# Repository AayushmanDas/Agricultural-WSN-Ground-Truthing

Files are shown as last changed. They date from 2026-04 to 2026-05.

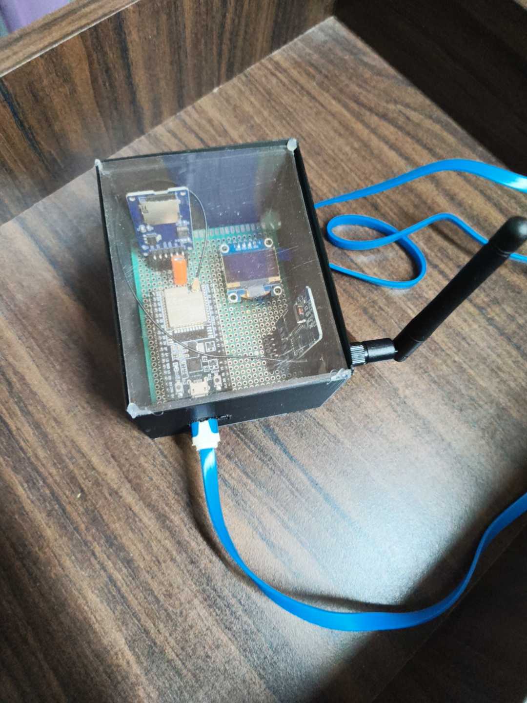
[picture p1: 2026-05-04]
media/images/IMG_20260322_044031079.jpg

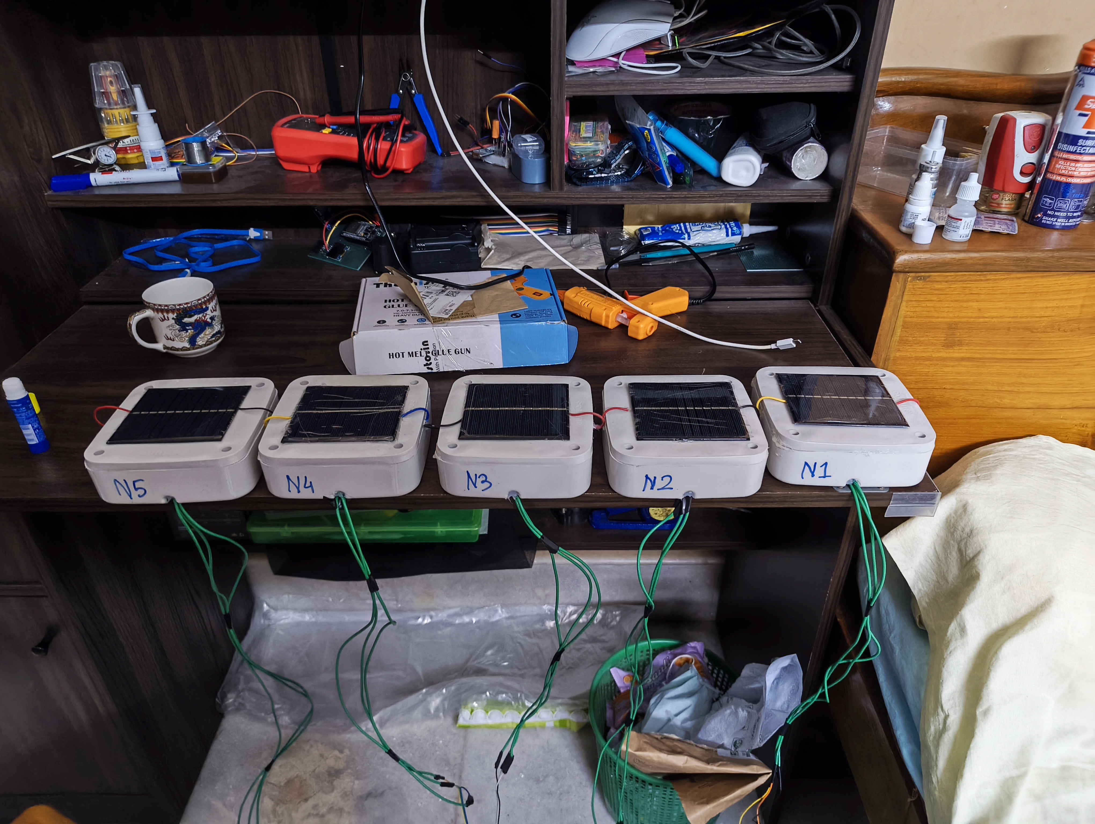
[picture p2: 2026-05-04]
media/images/IMG_20260323_042032066.jpg

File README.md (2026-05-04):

# Agricultural WSN Ground-Truthing
**Bridging the gap between orbital soil moisture observations and high-fidelity terrestrial in-situ data.**






## 📡 Research Objective
This framework is an end-to-end Wireless Sensor Network (WSN) designed to provide a local baseline for the validation of NASA's SMAP (Soil Moisture Active Passive) satellite products. By deploying synchronized sensor nodes in tropical micro-climates, the system identifies localized discrepancies that 9km orbital estimates cannot resolve.

## 🚀 Key Research Findings
* **Urban Resolution Gap:** Identified a **39.30% RMSE** discrepancy between orbital data and ground truth, suggesting significant spatial averaging bias in regional satellite products.
* **Environmental Resilience:** Maintained 100% data continuity for critical reference nodes during a **severe hailstorm (March 26)** through a triple-redundant logging pipeline.
* **Hydrological Dynamics:** Captured distinct moisture drying slopes ($m \approx -4.2\%/day$) influenced by urban verticality and micro-climatic "pockets."

## 🏗️ Technical Architecture
* **Protocol:** Optimized **ESP-NOW** (1 Mbps Long Range) for robust peer-to-peer data acquisition through reinforced concrete environments.
* **Power Management:** Custom Li-ion harvesting with **HT7333-A LDOs** (4µA quiescent current) and deep-sleep optimization for maximum field longevity.
* **Triple-Redundancy Pipeline:** 1. **Local:** Real-time OLED telemetry.
    2. **Edge:** SPI-based SD card logging (DS3231 RTC synchronized).
    3. **Cloud:** PostgreSQL (Supabase) sync via asynchronous Wi-Fi handshakes.

## 📂 Repository Structure
* **/firmware** - Source code for Central Hub & Remote Nodes.
* **/hardware** - Fusion 360 CAD models, KiCad schematics and BOM.
* **/scripts** - Python scripts for heuristic noise reduction and NASA SMAP correlation.
* **/docs** - Full IEEE-format technical paper and technical abstract.
* **/media** - Images and Video links showcasing the production procedure.

## 🛠️ Hardware Specifications
| Component | Detail |
| :--- | :--- |
| **Microcontroller** | ESP32-WROOM-32 |
| **Atmospheric Sensor** | BME280 (Temperature, Humidity, Pressure) |
| **Soil Sensor** | Capacitive v1.2 (Potded/Ruggedized) |
| **Regulation** | HT7333-A Low-Dropout Regulator |
| **Casing** | Custom 3D-printed Hub + IP65 Field Enclosures |

## ⚖️ Citation
If you utilize this framework or dataset, please cite the preprint:
> Das, A. (2026). "Robustness Evaluation of a Low-Cost WSN for Satellite Ground-Truthing under Extreme Tropical Weather Events." ResearchGate. DOI: [10.13140/RG.2.2.25746.00967](https://doi.org/10.13140/RG.2.2.25746.00967)

---
**Maintained by Aayushman Das** *Department of Electronics and Telecommunication Engineering, Jadavpur University*

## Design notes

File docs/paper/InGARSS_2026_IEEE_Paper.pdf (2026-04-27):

# Robustness Evaluation of a Low-Cost WSN for Satellite Ground-Truthing under Extreme Tropical Weather Events

Aayushman Das
Department of Electronics and Telecommunication Engineering Jadavpur University
Kolkata, India
aayushmand.etce.ug@jadavpuruniversity.in

Abstract—Satellite missions like NASA’s SMAP provide global soil moisture estimates but their 9km spatial resolution necessitates terrestrial validation. However, deploying low-cost Wireless Sensor Networks (WSNs) in tropical micro-climates presents significant reliability challenges. This paper evaluates the performance of an ESP32 based 5-node Wireless Sensor Network (WSN) during a hailstorm and subsequent thunderstorm events in West Bengal. Utilizing the ESP-NOW protocol and a tripleredundant data pipeline (OLED, SD, Cloud), we analyze system resilience and sensor recovery dynamics. Despite a high node attrition rate due to extreme precipitation, the framework maintained data continuity for critical reference nodes. Our findings hope to show that modularity and redundancy are vital for validation systems where environmental ”failure points” define the boundaries of satellite-to-ground correlation.
Index Terms—Wireless Sensor Networks, Ground-Truthing, ESP32, ESP-NOW, NASA SMAP, Soil Moisture, Triple Redundant Pipeline.
I. INTRODUCTION

Satellite data is essential to contemporary environmental science however, its lack of spatial resolution restricts its use in small-scale farming. For example, NASA’s SMAP mission usually yields a reading every 9 kilometers. Inaccurate averages for specific farm plots may result from this. There is a ”trust-gap” in remote sensing for regional use, as evidenced by a local survey of over 50 respondents, which revealed that about 80% of users trust a local sensor more than a satellite reading. Reliable, inexpensive terrestrial systems are obviously needed to confirm what satellites are seeing from orbit [1]. Our goal at Jadavpur University is to develop high-precision research instruments on a tight budget. The objective is to achieve industrial-grade reliability without the expense of pricey commercial equipment, much like ISRO’s inventiveness. Long-range work frequently uses protocols like LoRa, but each node needs extra hardware to use them. Rather, we improved the ESP-NOW protocol, which is integrated into the ESP32. We established a reliable link that can pass through four to five layers of reinforced concrete by utilizing 1 Mbps Long Range mode and high-gain SMA antennas at the hub. While commercial agro-meteorological stations (e.g., Davis Vantage Pro2) offer high accuracy, their cost-per-node (>500

USD) makes high density urban deployment problematic [8]. Our ESP32-based architecture, costing ≈ 15 USD per node, provides a scalable alternative for capturing the high spatial variance of urban micro-climates [11].
The goal of this study is to determine the correlation error between orbital estimates and ground truth while evaluating the structural resilience of the WSN itself. The setup maintains its scientific validity even in the event of hardware or network disruptions by utilizing a triple redundant data pipeline (OLED, SD and Cloud). A unique aspect of this deployment was the occurrence of a severe hailstorm during the 14 day window, which turned the project into a stress test for low-cost hardware. Python is used to process the data and for filtering out hardware artifacts caused by moisture deposition. The source code and hardware design files are available at https://github.com/AayushmanDas/Agricultural-WSN-Ground-Truthing. (https://github.com/AayushmanDas/Agricultural-WSN-Ground-Truthing)

II. METHODOLOGY

A. Node Hardware Design and Power Management

The sensor nodes can function independently for extended periods of time in agricultural settings with high humidity. Each node is powered by a single 18650 Li-ion battery that is charged using a TP4056 module and a 6V 250mA solar panel. Power is controlled by an HT7333-A Low-Dropout (LDO) regulator, which was chosen for its extremely low quiescent current (4µA) to reduce current draw during inactive times. In order to save energy, the ESP32 uses a Deep Sleep cycle, sending data ”chirps” every 30 minutes and staying in a lowpower state the rest of the time.
The sensors consisted of a BME280, for atmospheric data and a capacitive soil moisture probe. The BME280 is configured for I2C communication, the CS pin is pulled high to force I2C mode, and the SDO pin is tied to 3.3V to lock the I2C address at 0x77. Soil moisture is monitored via an analog-to-digital converter (ADC) on GPIO 34 [4], [5]. A 25V rated voltage divider (7kΩ/10kΩ) provides battery telemetry, allowing the system to monitor charge cycles.

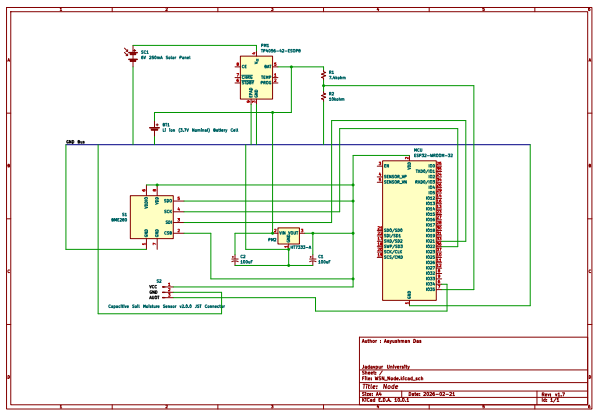
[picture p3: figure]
D Date: 2026-02-21; KiCad E.D.A. 10.0.1; Size: A4; Rev: v1.7; Title: Node; File: WSN_Node.kicad_sch; Sheet: /; Jadavpur University; Author : Aayushman Das; TEMP 1 PROG 2 GND; V CC 4 BAT 5; STDBY 6 CHRG 7 CE 8; EPAD; TP4056-42-ESOP8; GND; 1 VDD; SENSOR_VP 4 SENSOR_VN 5; SHD/SD2 17 SWP/SD3 18 SCS/CMD 19 SCK/CLK 20; SDO/SD0 21 SDI/SD1 22; IO21 33 RXD0/IO3 34; TXD0/IO1 35; IO23 37 MCU; ESP32-WROOM-32 R1 7.4kohm; R2 10kohm; SC1 6V 250mA Solar Panel BT1; Li ion (3.7V Nominal) Battery Cell; 100uF GND; 1 CSB 2; SDI 3; SCK 4; SDO 5 VDDIO; 6 GND 7 VDD; S1 BME280; VIN 2; VOUT 3 PM2; AUOT GND Bus; VCC

S2 Capacitive Soil Moisture Sensor v2.0.0 JST Connector | C2

Fig. 1. Circuit diagram of the solar-powered sensor node. Key components include the HT7333-A LDO for low-quiescent current and the TP4056

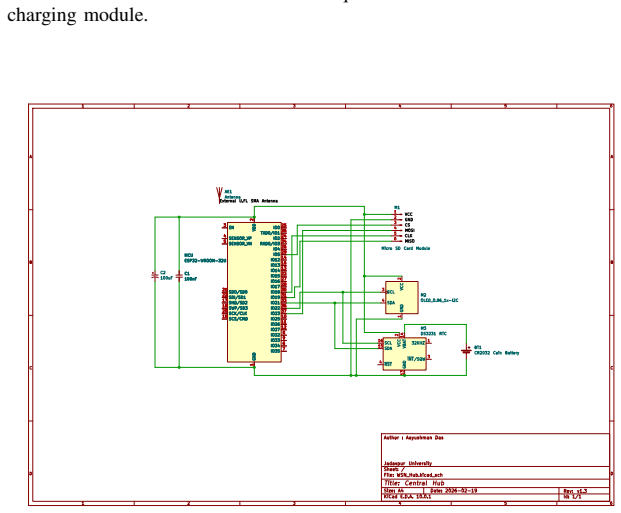
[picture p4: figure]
charging module. 1; D Date: 2026-02-19; KiCad E.D.A. 10.0.1; Size: A4; Rev: v1.3; Title: Central Hub; File: WSN_Hub.kicad_sch; Sheet: /; Jadavpur University; Author : Aayushman Das C2; GND; 1 VDD; SENSOR_VP 4 SENSOR_VN 5; SHD/SD2 17 SWP/SD3 18 SCS/CMD 19 SCK/CLK 20; SDO/SD0 21 SDI/SD1 22; IO21 33 RXD0/IO3 34; TXD0/IO1 35; IO23 37 MCU ESP32-WROOM-32U; AE1 Antenna C1; INT/SQW 3 RST 4; GND 13 VBAT 14; SDA 15 SCL 16; M3 DS3231 RTC GND; 1 VCC; SCL 3; SDA 4; M2 OLED_0.96_1x-I2C; VCC; CSCLK MISO MOSI C1; 100nF MCU; ESP32-WROOM-32U

100nF | BT1 CR2032 Coin Battery 32KHZ 1 VCC
6M1 Micro SD Card Module External U.FL SMA Antenna | GND

Fig. 2. Gateway (Hub) schematic illustrating the SPI interface for the SD module and the I2C bus sharing between the 0.96 inch SSD1306 OLED and DS3231 RTC module.

B. Gateway (Hub) Architecture and Redundancy

The hub serves as a link between the cloud and the local WSN. It has an 0.96 inch OLED for telemetry and a DS3231 Real Time Clock (RTC) Module to preserve time-stamping accuracy during power cycles. It is powered by a 5V micro USB supply. To avoid data loss during network outages, data is locally stored on an SPI-based SD card module.
A Triple Redundant Data Pipeline was used, aiming to improve data integrity. The Hub uploads a snapshot of the most recent data to a Supabase PostgreSQL database every three hours, but it gives priority to ESP-NOW packet reception. The WiFi stack only initialises if no node packets have been received in the previous 5-minute buffer, preventing radio interference.
C. Firmware Implementation and Time-Division Radio Multiplexing
It takes careful timing to manage two different radio protocols on the same 2.4 GHz antenna. It was necessary to use a Time-Division Hardware Re-initialization strategy because standard 802.11 WiFi and 1 Mbps Long Range ESP-NOW (fixed on Channel 1) cannot work at the same time without losing a ton of packets [3]. The Hub’s default setting is to keep an active ESP-NOW listening state. When the threehour cloud-sync timer goes off, the firmware does a Complete Radio De-initialization. This clears the ESP-NOW stack from memory and sets up the hardware registers for a standard WiFi handshake. The ArduinoJson library serialises the data, and an asynchronous HTTP POST request sends it to the Supabase REST API. Once a ”200 OK” response is verified, the WiFi stack is terminated, and the radio is recalibrated back to its high gain ESP-NOW state.
D. Enclosure and Environmental Ruggedization
The Hub enclosure was modeled in Fusion 360 and 3D printed using PLA material (20% infill, 78g). The field nodes are placed in IP65-rated enclosures. To withstand the humid climate, all wire entry points were sealed with neutral silicone sealant and hot glue. A semi permeable vent was placed at the base of each box to allow airflow for the BME280 while blocking entry of insects like ants and spiders.
The capacitive soil sensors underwent a ”potting” process, where exposed surface-mount components were coated in silicone to prevent oxidation. Nodes were deployed with the enclosures elevated 0.5m above the ground to improve Fresnel zone clearance.
E. Deployment and Field Observation
In order to track a 14 day cycle, the system was installed in a home garden in Kolkata, West Bengal. Nodes were positioned 0.5m above the ground, in order to improve link quality. The network’s average Received Signal Strength Indicator (RSSI) was consistently between -80 to -85 dBm, according to real time telemetry on the Hub’s OLED interface.
The optimized 1 Mbps Long Range mode maintained a stable link despite the highly resistive path to Node 4, which required diagonal signal penetration through approximately 0.8m of reinforced concrete. A modular hardware design facilitated rapid field recovery following a mechanical impact on Node 1 during the initial deployment. While the impact compromised the soil probe and voltage divider, the digital I2C atmospheric sensor remained operational. This incident led to a design iteration where all node mounting points were secondary reinforced with fasteners, increasing the structural damping of the enclosures for the remainder of the study.
F. Environmental Stress and Node Attrition
The 14-day observational window was characterized by significant meteorological volatility, including a localized hailstorm on March 26, 2026, followed by recurring thunderstorms. These events resulted in a 60% network attrition rate, providing a natural stress-test for the system. Node 1 experienced terminal power failure, while Nodes 3 and 4 showed oscillator stall issues, a state where moisture deposition on the capacitive sensor heads shifts the resonant frequency beyond operational bounds. Conversely, Node 2 (elevated at 1.5m) and Node 5 (terrace-mounted) maintained data continuity. This suggests that high-ventilation placement is more critical for long term IP65 enclosure integrity than physical shielding, as the sheltered nodes suffered from moisture trapping and prolonged humidity exposure.

III. DATA POST-PROCESSING AND ANALYTICS

A. Heuristic Noise Reduction and Outlier Filtering
Raw field data from the WSN exhibited significant stochastic noise, primarily attributed to high-frequency dielectric fluctuations during extreme precipitation. To ensure scientific integrity, a multi-stage Python-based cleaning pipeline was implemented.
- Hard-Clamp Filter: A signal-to-physical range mapping was applied to moisture readings. Values below 30% (designating dry-air reference) and above 100% (saturation) were designated as null (N aN). This eliminated hardware-induced transients and ADC jitter caused by supply voltage fluctuations during solar charging cycles.
- Stale-Data Detector: To identify sensor freezing, a rolling standard deviation filter monitored readings over a 6 hour window (12 samples). Any node exhibiting zero variance (σ = 0) was flagged as an oscillator stall and excluded. This condition typically occurs when moisture deposition on the capacitive sensor head shifts the resonant frequency beyond the operational bounds of the internal timer circuit.
- Timestamp Correction: Due to the absence of a global clock on individual nodes, temporal drift was corrected by the Hub’s DS3231 RTC. Records with corrupted Unix timestamps (e.g., year 2045 artifacts) were re-mapped based on the sequential index of the SD card logs.
B. Spatial-Temporal Alignment with Orbital Products
NASA SMAP (Level-3 Passive) data provides a singular daily estimate at a 9km spatial resolution. Conversely, the WSN provided 48 samples per day (30-minute chirps). To allow for cross-validation, the WSN dataset was down sampled using a nearest neighbor temporal join to the specific overpass timestamp provided in the SMAP metadata [2]. This attempts to ensure that ground-truth data reflected the exact soil state at the moment of orbital sensing.

IV. EXPERIMENTAL RESULTS AND DISCUSSION

A. Network Resilience and Attrition Dynamics
As illustrated in Fig. 3, the network faced severe environmental stress during the localized hailstorm on March 26, 2026. While Nodes 1, 3, and 4 suffered hardware failure, Node 2 and Node 5 maintained continuity.
This disparity in survival provides critical insights into urban WSN deployment. Nodes 3 and 4 were ”sheltered” under a canopy, which paradoxically led to their failure, the canopy trapped high humidity and slowed evaporation, leading to prolonged moisture deposition in the enclosures. Conversely, Node 2 (elevated at 1.5m) and Node 5 (terrace-mounted) benefited from higher wind velocity and ventilation, which facilitated rapid drying of the external housing. This suggests that for tropical WSNs, ventilation is a more effective strategy than physical shielding for long term use cases.

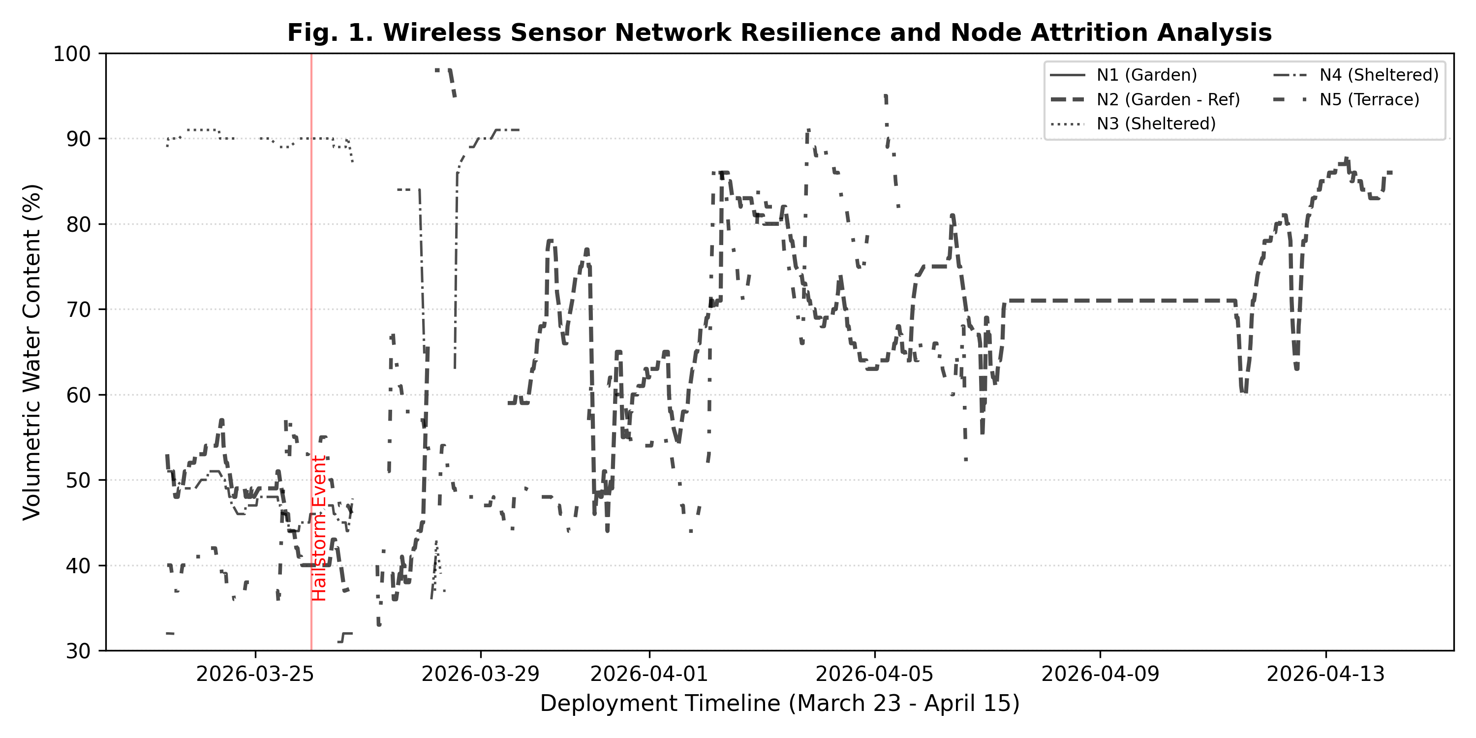
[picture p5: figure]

Fig. 3. WSN Attrition Analysis: Visualization of node failure points relative to the March 26 hailstorm ingress. Discontinuities represent data cleaning via the stale-data filter.

B. Vertical Microclimate Variance
A significant moisture gradient was observed between ground-level (Node 2) and terrace-level (Node 5) deployments (Fig. 4). While both nodes recorded a saturation spike during the hailstorm, Node 5 exhibited a steeper drying slope (m ≈ −4.2%/day).
This confirms that urban verticality influences moisture retention. High-elevation ”pockets” (terraces) experience different evaporative microclimates than ground-level gardens. Because satellite sensors (9km pixels) average these heights into a single value, they fail to resolve the distinct hydrological behaviors required for precision urban agricultural management.

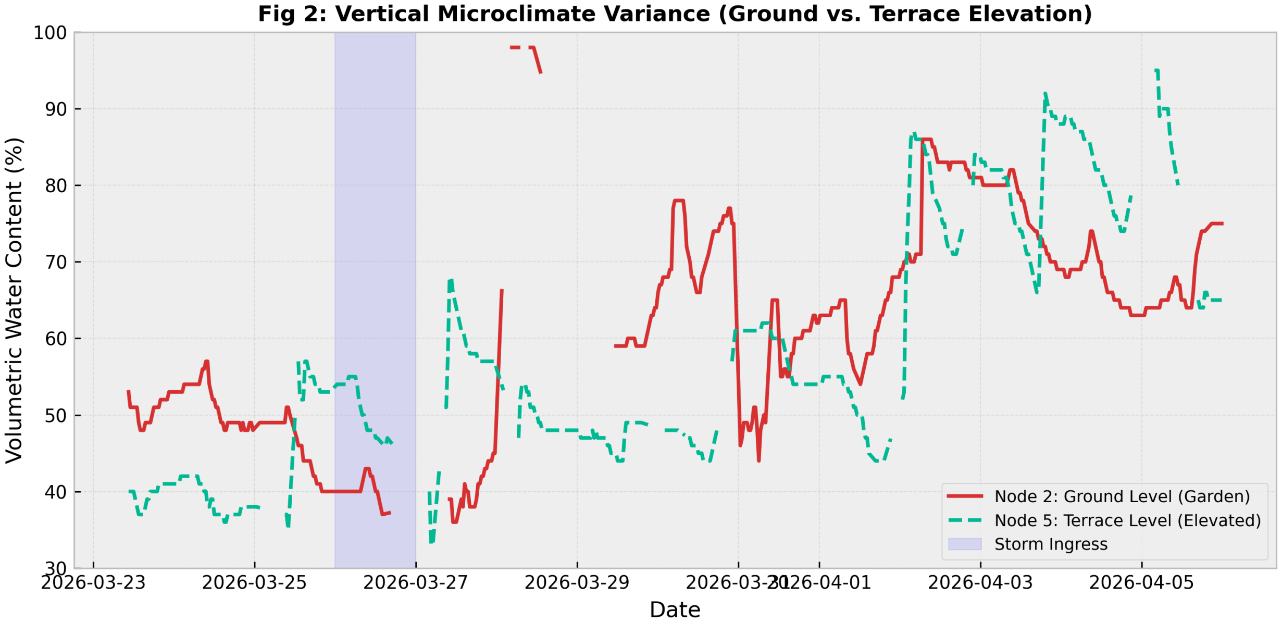
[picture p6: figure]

Fig. 4. Vertical Microclimate Variance: Comparing Ground-Truth (Node 2) vs. Terrace-Level (Node 5) moisture retention dynamics.

C. Satellite Validation and the ’Urban Bias’ Gap
The cross-validation against NASA SMAP (Fig. 5) yielded an RMSE of 39.30% and a correlation of -0.33. While these metrics initially suggest failure, in an urban context they highlight the Urban Resolution Gap [10]. The 9km SMAP footprint averages vast non-porous surfaces, resulting in a mean estimate (29.72%) that significantly underestimates localized vegetative hotspots (65.40%). The negative correlation further underscores the impact of anthropogenic factors, such as the shaded, manually-watered container at Node 5, which orbital sensors cannot resolve [7].

TABLE I
WSN VS. NASA SMAP ACCURACY METRICS SUMMARY
Metric | Value | Engineering Significance
RMSE (%) | 39.30% | Evidence of Spatial Averaging Bias
Trend Correlation (ρ) | -0.33 | Anthropogenic/Microclimate Decoupling
Mean WSN Value | 65.40% | High-Resolution In-Situ Ground Truth
Mean SMAP Value | 29.72% | Regional Coarse-Resolution Average

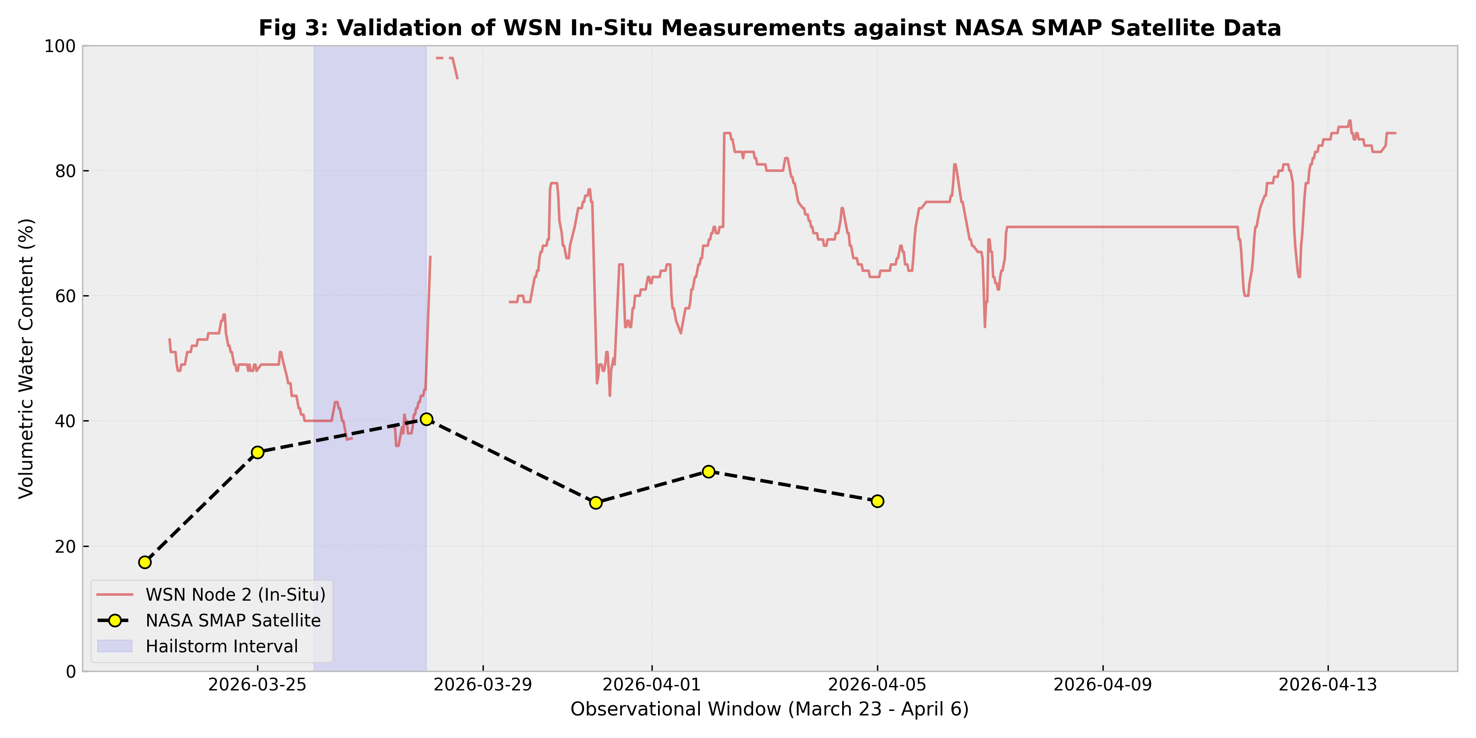
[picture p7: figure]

Fig. 5. In-Situ WSN vs. NASA SMAP: High RMSE highlights the Underestimation Bias in satellite products for urban vegetative hotspots.

V. LIMITATIONS AND FUTURE WORK
A. Study Limitations
We acknowledge that as a student led pilot study, the deployment scale was limited to five nodes within a specific residential microclimate. The 2 week observational window, while providing intense data during a hailstorm, may not capture long term seasonal shifts. Furthermore, the high attrition rate (60%) underscores that current low-cost IP65 enclosures require additional mechanical reinforcement to serve as permanent infrastructure in volatile tropical regions.
B. Concluding Remarks
Despite scale constraints, the surviving nodes exposed a critical underestimation bias in NASA’s SMAP product. Terrestrial WSNs proved to be essential corrective layers for achieving hydrological accuracy in urban centers where satellite pixels fail to resolve irrigation and verticality [6].
C. Future Research Directions
The results of this deployment establish a foundation for several engineering advancements:
- NISAR Integration: Future validation will prioritize NISAR’s high-resolution radar data to investigate if SAR products can bridge the 39.3% accuracy gap [9].
- Hardware Ruggedization: Testing superhydrophobic nano-coatings on enclosure vents to prevent moistureinduced frequency stalls.
- Edge-AI Implementation: Porting cleaning algorithms directly onto the ESP32 using TinyML for on-device autonomous outlier handling.
- Hybrid Power Management: Utilizing supercapacitorbattery hybrids to ensure 100% operational uptime, especially during monsoon periods.

ACKNOWLEDGMENT
The author acknowledges the assistance of LLMS, such as Gemini and Claude in manuscript preparation, specifically for language refinement, LaTeX formatting, and providing structural templates for software logic. These tools were utilized to optimize the C++ time-division radio firmware and refine the Python-based data cleaning scripts.
The author confirms that the physical hardware architecture, including solar power management and the 5-node WSN configuration and the 14-day field deployment were performed independently. While AI assisted in software logic and documentation, the author assumes responsibility for the manuscript’s conclusions and the overall scientific integrity of this paper.

REFERENCES

[1] D. Entekhabi et al., ”The Soil Moisture Active and Passive (SMAP) mission,” Proceedings of the IEEE, vol. 98, no. 5, pp. 704–716, May 2010, doi: 10.1109/JPROC.2010.2043918.
[2] A. Colliander et al., ”Validation of SMAP surface soil moisture products with core validation sites,” Remote Sensing of Environment, vol. 191, pp. 215–231, 2017, doi: 10.1016/j.rse.2017.01.021.
[3] Espressif Systems, ”RF Coexistence,” ESP-IDF Programming Guide, Espressif Systems (Shanghai) Co., Ltd., 2023. [Online]. Available: https://docs.espressif.com/projects/esp-idf/en/stable/esp32/apiguides/coexist.html
[4] A. A. Abdelmoneim, C. M. Al Kalaany, R. Khadra, B. Derardja, and G. Dragonetti, ”Calibration of Low-Cost Capacitive Soil Moisture Sensors for Irrigation Management Applications,” Sensors, vol. 25, no. 2, p. 343, Jan. 2025, doi: 10.3390/s25020343.
[5] P. Placidi, L. Gasperini, A. Grassi, M. Cecconi, and A. Scorzoni, ”Characterization of Low-Cost Capacitive Soil Moisture Sensors for IoT Networks,” Sensors, vol. 20, no. 12, p. 3585, Jun. 2020, doi: 10.3390/s20123585.
[6] L. Brocca, L. Ciabatta, C. Massari, S. Camici, and A. Tarpanelli, ”Soil Moisture for Hydrological Applications: Open Questions and New Opportunities,” Water, vol. 9, no. 2, p. 140, 2017, doi: 10.3390/w9020140.
[7] NASA SMAP Science Document No. 046, ”SMAP Ancillary Data Report: Urban Area,” Jet Propulsion Laboratory, Pasadena, CA, USA, Tech. Rep., 2014. [Online]. Available: https://smap.jpl.nasa.gov/
[8] N. Ahmad, A. Hussain, I. Ullah, and B. H. Zaidi, ”IOT based Wireless Sensor Network for Precision Agriculture,” in Proc. iEECON, 2019, pp. 1–4, doi: 10.1109/iEECON45304.2019.8938854.
[9] P. Rosen et al., ”The NASA-ISRO SAR Mission: A summary,” IEEE Geosci. Remote Sens. Mag., 2025, doi: 10.1109/MGRS.2025.3578258.
[10] W. Liu et al., ”Validation of Four Satellite-Derived Soil Moisture Products Using Ground-Based In Situ Observations over Northern China,” Remote Sens., vol. 14, no. 6, p. 1419, 2022, doi: 10.3390/rs14061419.
[11] S. Majumder et al., ”Assessing Low-cost Capacitive Soil Moisture Sensors: Accurate, Affordable, and IoT-ready Solutions for Soil Moisture Monitoring,” Int. J. Environ. Clim. Change, vol. 13, no. 11, pp. 2233– 2242, 2023, doi: 10.9734/ijecc/2023/v13i113386.

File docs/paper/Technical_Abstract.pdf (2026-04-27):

# Architecture of a Ground-Truthing System for Verified Agricultural Wireless Sensor Networks

Aayushman Das
Department of Electronics and Telecommunication Engineering Jadavpur University, Kolkata, India Documentation and Source Code: https://github.com/AayushmanDas/Agricultural-WSN-Ground-Truthing

Abstract

This project outlines an empirical architecture for a 5-node Wireless Sensor Network (WSN) designed to validate NASA SMAP orbital soil moisture data against localized terrestrial measurements. Due to the 9km spatial resolution of satellite products, urban and tropical micro-climates often suffer from high signal variance that necessitates high-fidelity ground-truthing.
The system is built on the ESP-NOW protocol, utilizing a high-gain 1 Mbps Long Range mode for penetration through environmental obstacles. Hardware nodes feature HT7333-A LDO regulators for ultra-low quiescent current consumption (4µA), supported by solarcharged 18650 Li-ion arrays for autonomous operation. A triple-redundant data pipeline was implemented—consisting of local SD logging, real-time OLED telemetry, and a Supabase cloud uplink—to ensure data persistence during extreme weather. Deployment during a localized hailstorm in West Bengal validated the system’s resilience, revealing a 39.30% RMSE bias in satellite data for urban hotspots. This framework demonstrates a scalable, low-cost method for correcting spatial averaging in remote sensing through high-fidelity IoT telemetry.

Keywords: Ground Truthing, NASA SMAP, ESP-NOW, Triple Redundant Pipeline, HT7333-A LDO, Urban Resolution Gap.

1

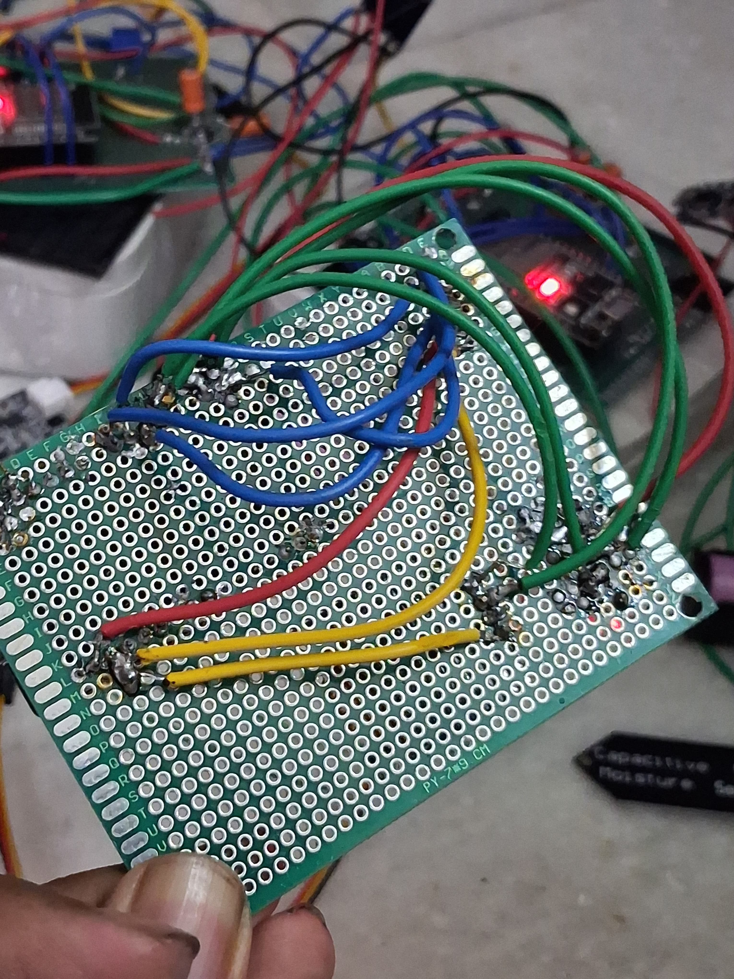
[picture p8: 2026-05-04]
media/images/IMG-20260217-WA0008.jpg

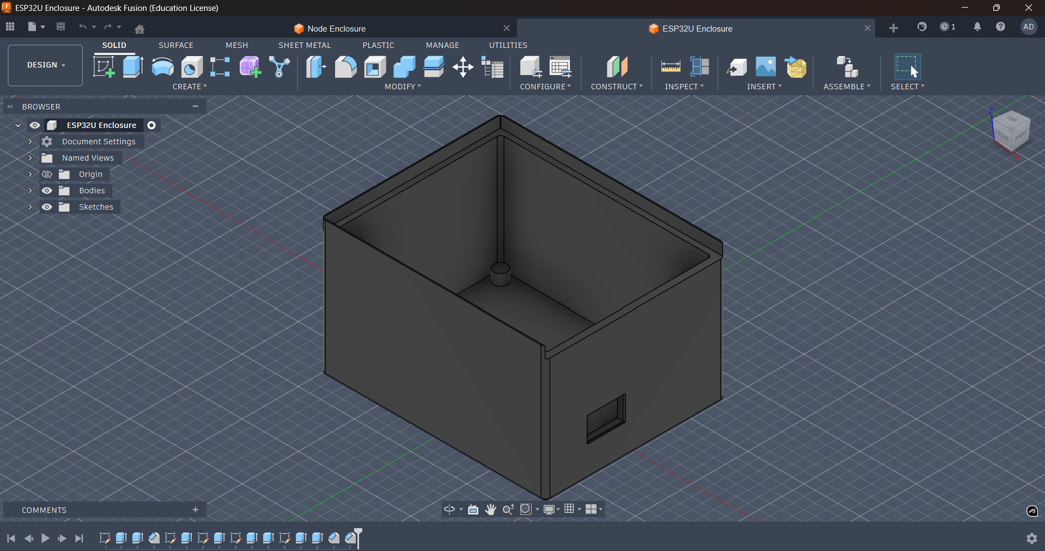
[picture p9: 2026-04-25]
media/images/1_ESP32U Enclosure Isometric View.png

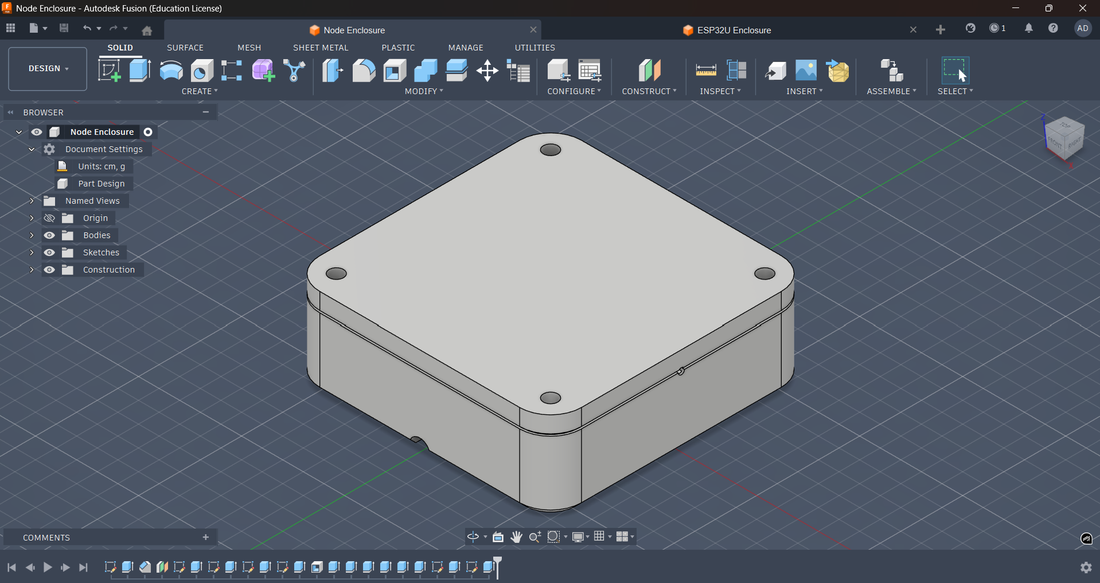
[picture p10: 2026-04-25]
media/images/5_Node Enclosure Isometric View.png

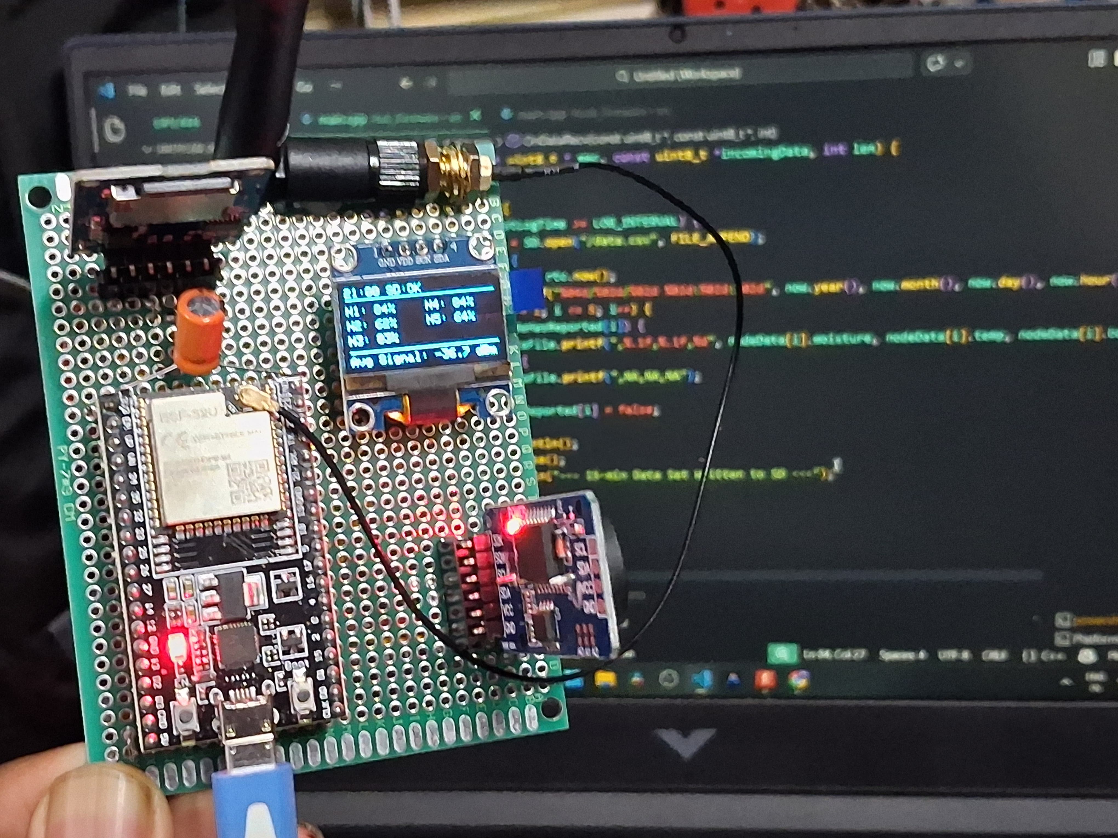
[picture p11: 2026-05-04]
media/images/IMG-20260217-WA0012.jpg

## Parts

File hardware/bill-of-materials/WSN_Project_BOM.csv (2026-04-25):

Category | Component | Specification | Purpose | Qty (Total)
Microcontrollers | ESP32-WROOM-32U | 38-Pin Wide (U.FL connector) | Central Hub MCU | 1
 | ESP32-WROOM-32 | 30-Pin Standard | Remote Node MCU | 5
Sensors | BME280 | I2C (Temp/Humid/Pressure) | Atmospheric Ground-Truthing | 6
 | SEN0193 | Capacitive Soil Moisture | Terrestrial Soil Moisture | 5
 | Voltage Sensor | VCC < 25V (0.1V Res.) | Battery/Solar Monitoring | 5
Power (Node) | HT7333-A | 3.3V Low Dropout (LDO) | Ultra-low power regulation | 5
 | TP4056 | 1A Li-ion Charging Module | Solar charging controller | 5
 | Solar Panel | 5V / 250mW (Monocrystalline) | Energy harvesting | 5
 | 18650 Battery | 3.7V Li-ion (2600mAh+) | Node power source | 5
Power (Hub) | Wall Adapter | 5V 1A Micro-USB/Type-C | Continuous Hub power | 1
Storage/Time | Micro SD Module | SPI Interface (5V Compatible) | Local Data Redundancy | 1
 | DS3231 RTC | I2C High-Accuracy Clock | Precise Data Timestamping | 1
Peripherals | OLED Display | 0.96" I2C (128x64) | Real-time Hub Telemetry | 1
 | SMA Antenna | 2.4GHz High Gain (External) | Long-range ESP-NOW link | 1
Hardware | IP65 Enclosures | Waterproof ABS Plastic | Field node protection | 5
 | Connectors | JST-PH 2.0 / Screw Terminals | Modular wiring | 10+

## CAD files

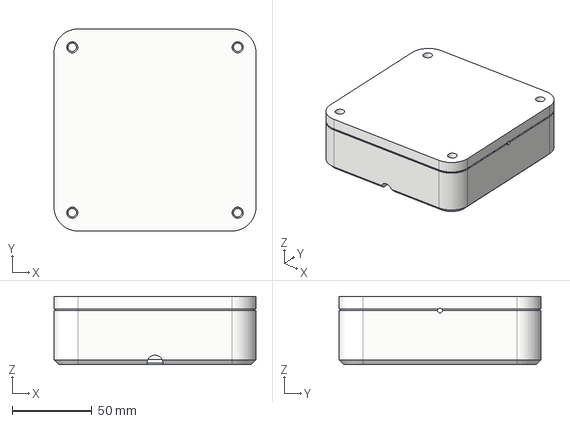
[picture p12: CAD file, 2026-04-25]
hardware/cad-models/Node Enclosure.step
127.0 x 127.0 x 43.0 mm

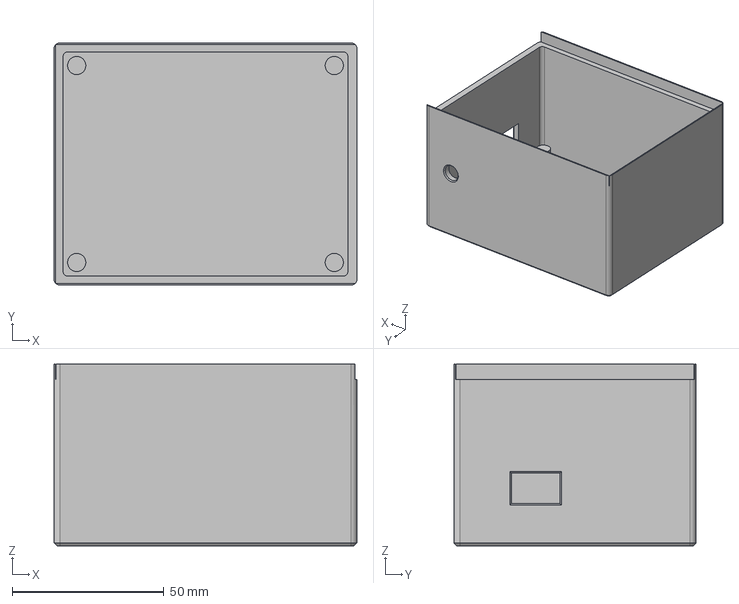
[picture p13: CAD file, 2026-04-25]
hardware/cad-models/ESP32U Enclosure.step
100.0 x 80.0 x 60.0 mm

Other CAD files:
hardware/cad-models/ESP32U Enclosure.f3d
hardware/cad-models/Node Enclosure.f3d

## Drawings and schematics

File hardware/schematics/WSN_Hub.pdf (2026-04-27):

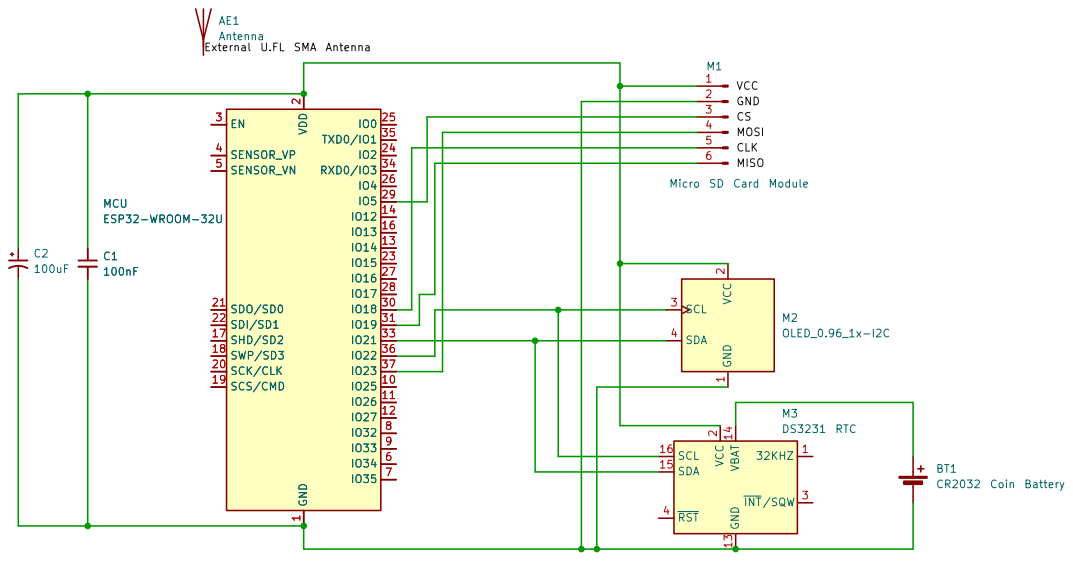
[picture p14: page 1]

Size: A4 | Rev: v1.3
KiCad E.D.A. 10.0.1 | Id: 1/1

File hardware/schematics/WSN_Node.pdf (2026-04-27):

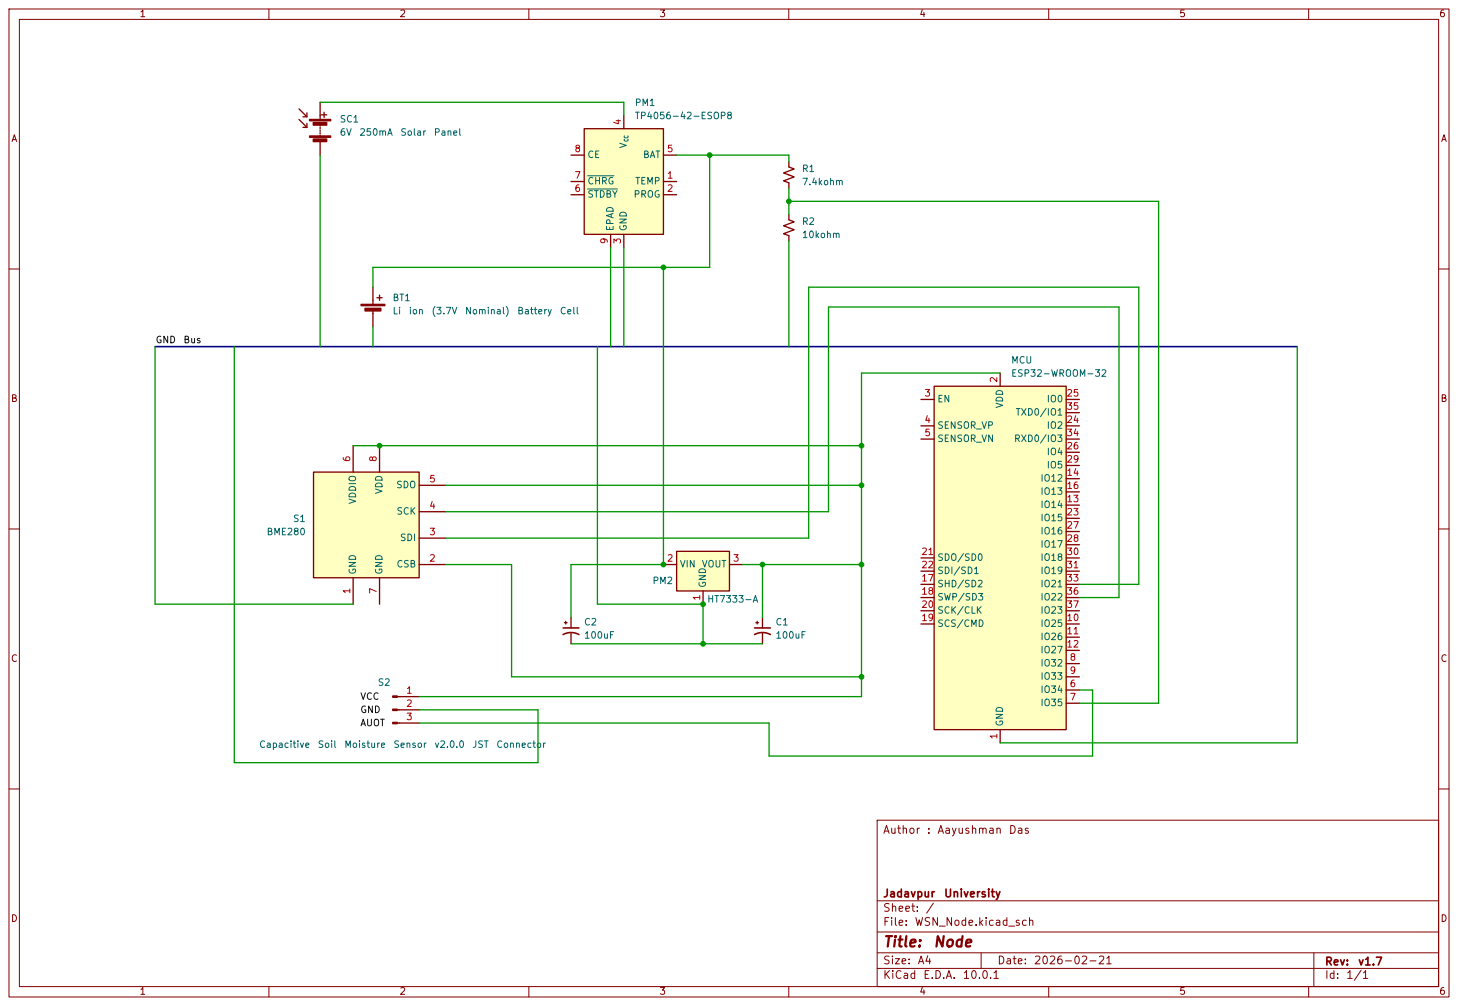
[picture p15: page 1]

Size: A4 | Rev: v1.7
KiCad E.D.A. 10.0.1 | Id: 1/1

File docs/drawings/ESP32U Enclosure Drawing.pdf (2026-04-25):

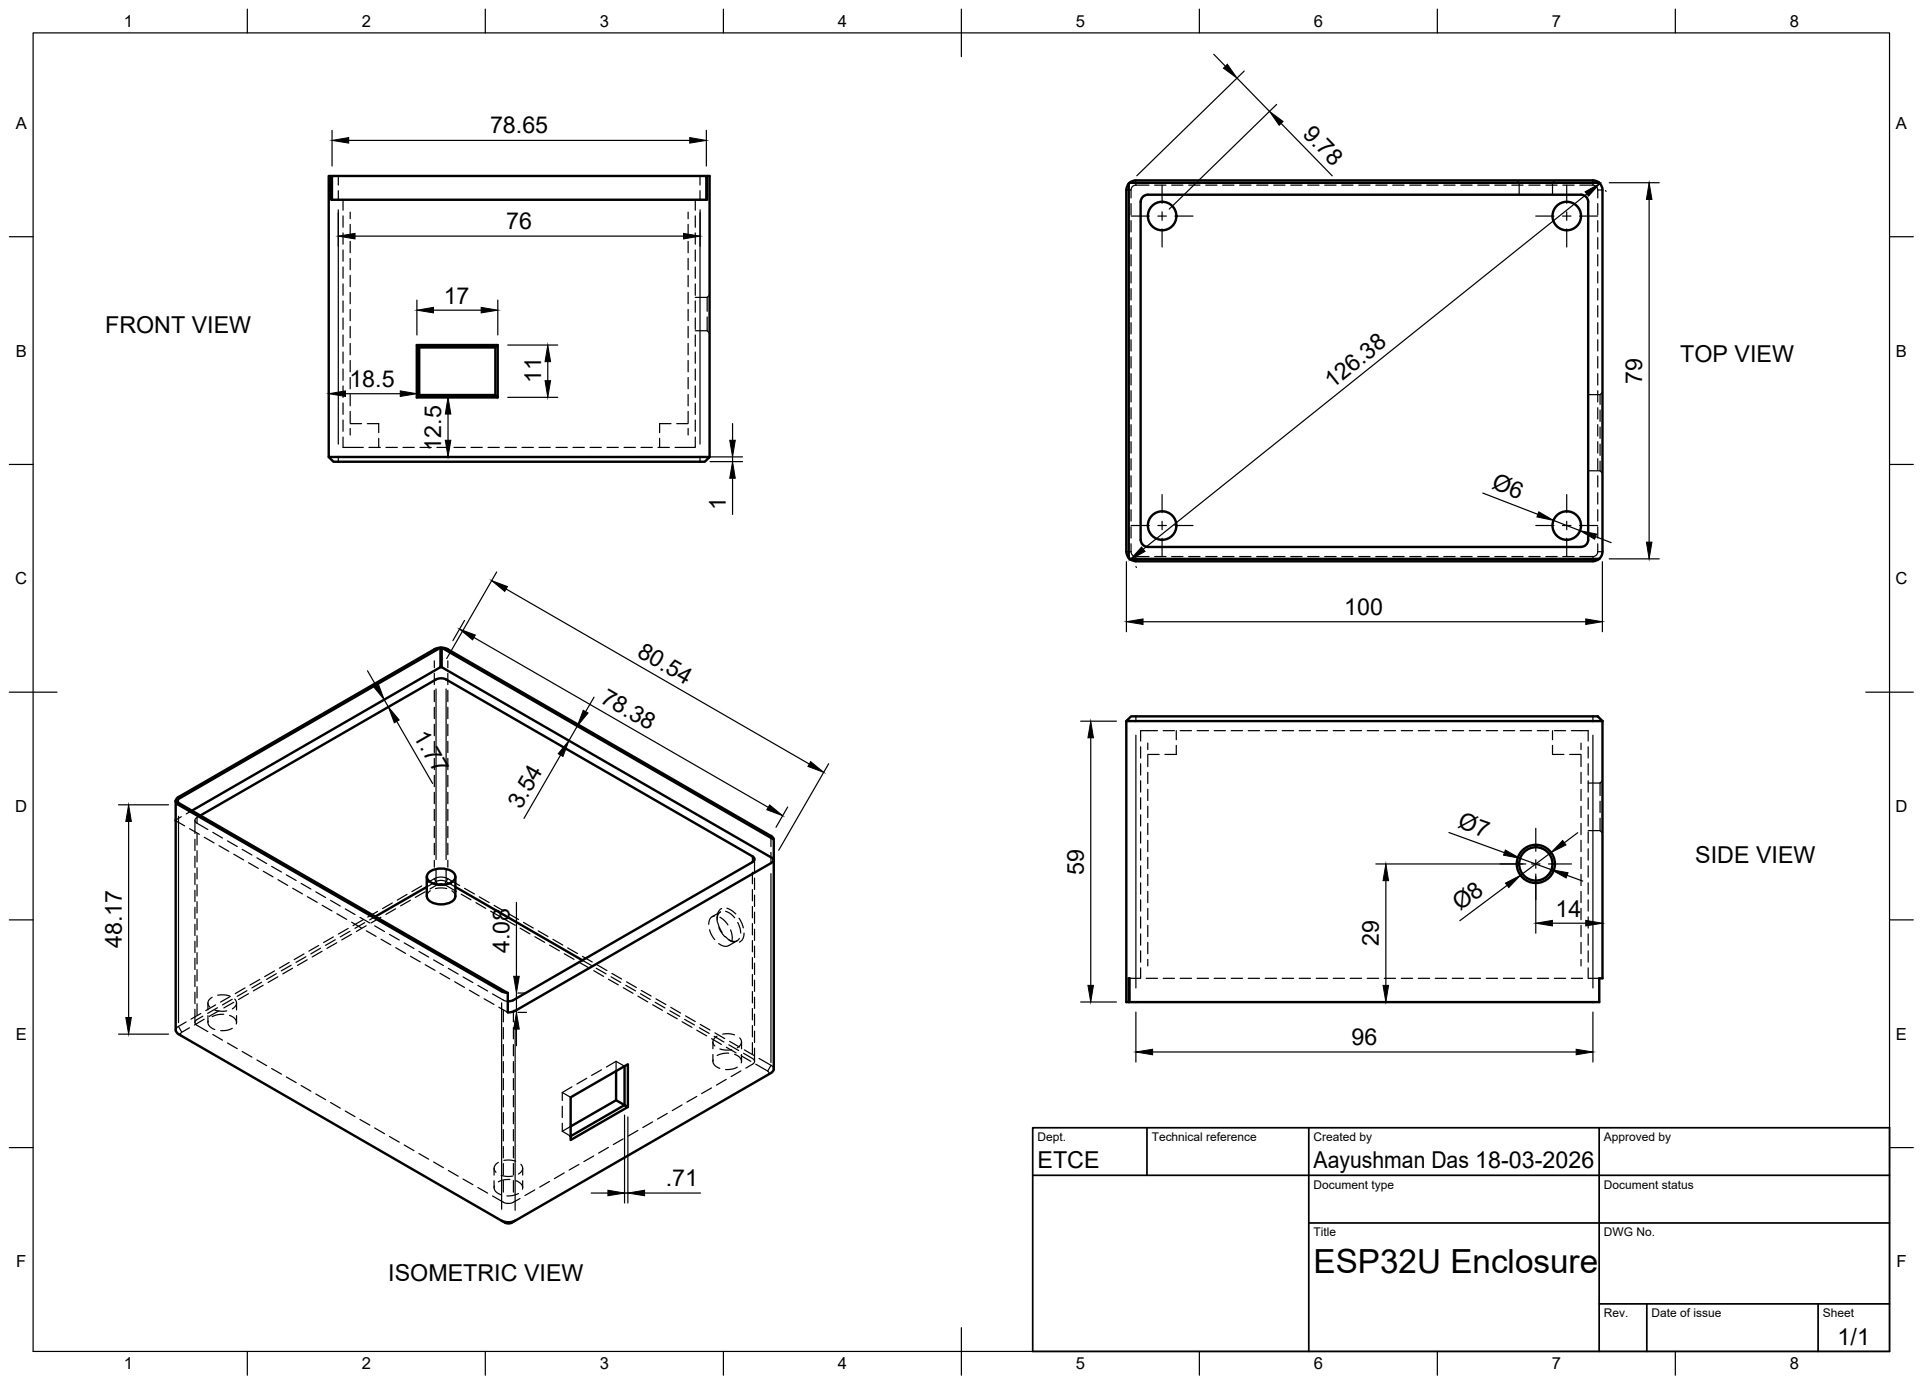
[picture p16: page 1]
Title; DWG No.; Rev.; Date of issue; Sheet; ESP32U Enclosure; TOP VIEW; SIDE VIEW; FRONT VIEW; ISOMETRIC VIEW

Dept. ETCE | Technical reference | Created by Aayushman Das 18-03-2026 | Approved by

Document type | Document status

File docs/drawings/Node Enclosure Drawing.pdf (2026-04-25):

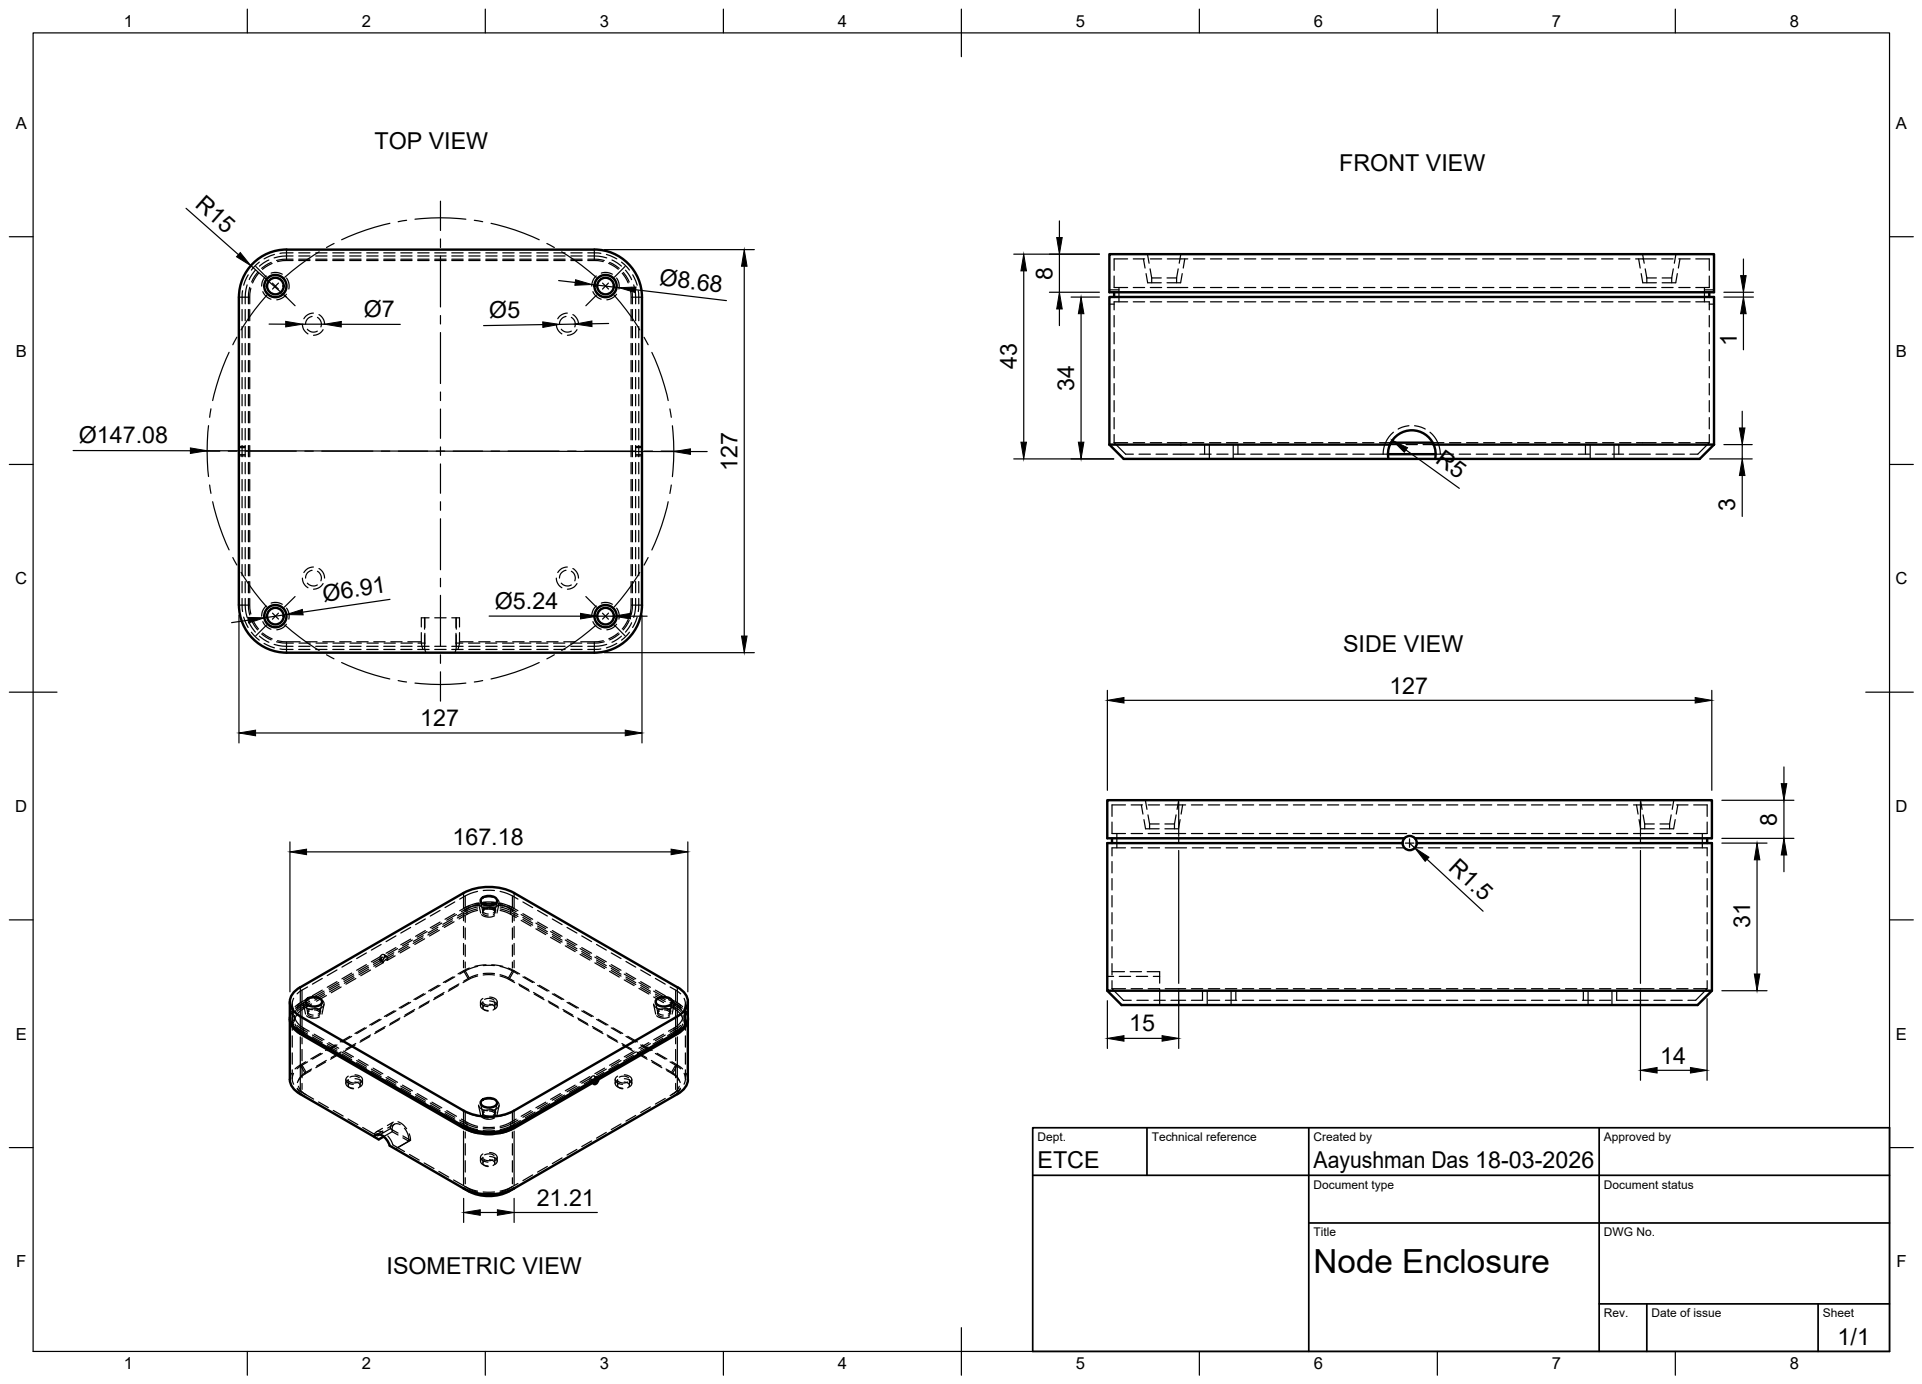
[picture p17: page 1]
Title; DWG No.; Rev.; Date of issue; Sheet; Node Enclosure; TOP VIEW; FRONT VIEW; SIDE VIEW; ISOMETRIC VIEW

Dept. ETCE | Technical reference | Created by Aayushman Das 18-03-2026 | Approved by

Document type | Document status

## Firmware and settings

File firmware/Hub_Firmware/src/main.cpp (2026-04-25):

/**
 * @file hub_main.cpp
 * @brief Central Gateway Firmware for Agricultural WSN Ground-Truthing
 * @description Manages ESP-NOW reception, SD-card persistence (now with Humidity), 
 * OLED telemetry, and scheduled Supabase sync.
 */

#include <Arduino.h>
#include <SPI.h>
#include <SD.h>
#include <Wire.h>
#include <Adafruit_GFX.h>
#include <Adafruit_SSD1306.h>
#include <RTClib.h>
#include <esp_now.h>
#include <WiFi.h>
#include <esp_wifi.h>
#include <HTTPClient.h>
#include <ArduinoJson.h>
#include "esp_private/wifi.h"
#include "secrets.h"

// ==============================================================================
// CONFIGURATION
// ==============================================================================
const char* WIFI_SSID = SECRET_SSID;
const char* WIFI_PASS = SECRET_PASS;
String supabase_url   = SECRET_SUPABASE_URL;
String supabase_key   = SECRET_SUPABASE_KEY;

#define SCREEN_WIDTH 128
#define SCREEN_HEIGHT 64
#define SD_CS_PIN 5
#define BOOT_BUTTON 0
#define RSSI_WINDOW 10

// Timing (ms)
const unsigned long LOG_INTERVAL  = 1800000;  // 30 Minutes
const unsigned long SYNC_COOLDOWN = 10800000; // 3 Hours
const unsigned long SYNC_MAX_TIME = 120000;   // 2 Minutes Failsafe

// ==============================================================================
// STRUCTURES & GLOBALS
// ==============================================================================
Adafruit_SSD1306 display(SCREEN_WIDTH, SCREEN_HEIGHT, &Wire, -1);
RTC_DS3231 rtc;

typedef struct struct_message {
    int id;
    float moisture;
    float temp;
    float humidity;
    int battPct;         
    unsigned int readingId; 
} struct_message;

struct_message nodeData[6];           
bool nodeHasReported[6] = {false};    

int rssiHistory[6][RSSI_WINDOW]; 
int rssiIndex[6] = {0};
bool sdStatus = false;
int latestRawRSSI = -100;

unsigned long lastRecvTime = 0;
unsigned long lastScreenUpdate = 0;
unsigned long lastLogTime = 0;
unsigned long lastSyncTime = 0;
unsigned long lastPulseTime = 0; 
bool isSyncing = false;

// ==============================================================================
// RADIO FUNCTIONS
// ==============================================================================
float getSmoothedRSSI() {
    long sum = 0;
    int count = 0;
    for (int n = 1; n <= 5; n++) {
        for (int i = 0; i < RSSI_WINDOW; i++) {
            if (rssiHistory[n][i] < 0 && rssiHistory[n][i] > -98) { 
                sum += rssiHistory[n][i];
                count++;
            }
        }
    }
    return (count == 0) ? 0 : (float)sum / count; 
}

void promiscuous_rx_cb(void* buf, wifi_promiscuous_pkt_type_t type) {
    wifi_promiscuous_pkt_t *p = (wifi_promiscuous_pkt_t*)buf;
    if (type == WIFI_PKT_DATA || type == WIFI_PKT_MGMT) {
        latestRawRSSI = p->rx_ctrl.rssi;
    }
}

void OnDataRecv(const uint8_t * mac, const uint8_t *incomingData, int len) {
    if (isSyncing) return; 
    
    struct_message temp;
    memcpy(&temp, incomingData, sizeof(temp));
    
    if (temp.id >= 1 && temp.id <= 5) {
        nodeData[temp.id] = temp;
        nodeData[temp.id].readingId = millis(); 
        nodeHasReported[temp.id] = true; 
        
        lastRecvTime = millis();
        lastPulseTime = millis(); 
        
        rssiHistory[temp.id][rssiIndex[temp.id]] = latestRawRSSI;
        rssiIndex[temp.id] = (rssiIndex[temp.id] + 1) % RSSI_WINDOW;
    }
}

void startESPNOW() {
    WiFi.disconnect(true);
    WiFi.mode(WIFI_OFF);
    delay(100); 
    
    WiFi.mode(WIFI_STA);
    esp_wifi_stop(); 
    esp_wifi_deinit();
    
    wifi_init_config_t my_config = WIFI_INIT_CONFIG_DEFAULT();
    my_config.ampdu_tx_enable = false; 
    esp_wifi_init(&my_config); 
    esp_wifi_start();

    esp_wifi_set_promiscuous(true);
    esp_wifi_set_channel(1, WIFI_SECOND_CHAN_NONE); 
    esp_wifi_set_promiscuous_rx_cb(&promiscuous_rx_cb);
    
    WiFi.setTxPower(WIFI_POWER_19_5dBm);
    esp_wifi_internal_set_fix_rate(WIFI_IF_STA, true, WIFI_PHY_RATE_1M_L);

    esp_now_deinit(); 
    if (esp_now_init() == ESP_OK) {
        esp_now_register_recv_cb(esp_now_recv_cb_t(OnDataRecv));
        Serial.println("ESP-NOW Ready");
    } else {
        ESP.restart();
    }
}

// ==============================================================================
// CLOUD SYNC
// ==============================================================================
void syncToSupabase() {
    isSyncing = true;
    unsigned long syncStart = millis();
    
    display.clearDisplay();
    display.setCursor(15, 25);
    display.print("SYNCING CLOUD...");
    display.display();

    WiFi.disconnect(true);
    WiFi.mode(WIFI_STA);
    WiFi.begin(WIFI_SSID, WIFI_PASS);

    while (WiFi.status() != WL_CONNECTED && (millis() - syncStart < 30000)) {
        delay(500);
    }

    if (WiFi.status() == WL_CONNECTED) {
        HTTPClient http;
        String endpoint = supabase_url + "/rest/v1/sensor_data";

        for (int i = 1; i <= 5; i++) {
            if (nodeData[i].id != 0) { 
                http.begin(endpoint);
                http.addHeader("apikey", supabase_key);
                http.addHeader("Authorization", "Bearer " + supabase_key);
                http.addHeader("Content-Type", "application/json");

                StaticJsonDocument<256> doc;
                doc["node_id"]     = nodeData[i].id;
                doc["moisture"]    = nodeData[i].moisture;
                doc["temp"]        = nodeData[i].temp;
                doc["humidity"]    = nodeData[i].humidity;
                doc["battery_pct"] = nodeData[i].battPct;
                
                String jsonStr;
                serializeJson(doc, jsonStr);
                http.POST(jsonStr);
                http.end();
            }
        }
        lastSyncTime = millis(); 
    }

    startESPNOW();
    isSyncing = false;
}

// ==============================================================================
// SD LOGGING
// ==============================================================================
void processAndLog() {
    if (millis() - lastLogTime >= LOG_INTERVAL) {
        File dataFile = SD.open("/data.csv", FILE_APPEND);
        if (dataFile) {
            sdStatus = true;
            DateTime now = rtc.now();
            dataFile.printf("%04d/%02d/%02d %02d:%02d:%02d", now.year(), now.month(), now.day(), now.hour(), now.minute(), now.second());
            
            for (int i = 1; i <= 5; i++) {
                if (nodeHasReported[i]) {
                    dataFile.printf(",M:%.1f,T:%.1f,H:%.1f,B:%d", 
                                    nodeData[i].moisture, nodeData[i].temp, 
                                    nodeData[i].humidity, nodeData[i].battPct);
                    nodeHasReported[i] = false; 
                } else {
                    dataFile.printf(",NA,NA,NA,NA"); 
                }
            }
            dataFile.println();
            dataFile.close();
        } else {
            sdStatus = false;
            SD.begin(SD_CS_PIN);
        }
        lastLogTime = millis();
    }
}

void handleSDWipe() {
    unsigned long startTime = millis();
    const unsigned long holdDuration = 3000; // 3 seconds
    
    while (digitalRead(BOOT_BUTTON) == LOW) {
        unsigned long elapsed = millis() - startTime;
        
        // Calculate progress for the bar (0 to 128 pixels wide)
        int progress = map(elapsed, 0, holdDuration, 0, 128);
        
        display.clearDisplay();
        display.setTextSize(1);
        display.setCursor(20, 15);
        display.print("HOLD TO WIPE SD");
        
        // Draw the Progress Bar Frame
        display.drawRect(0, 35, 128, 10, WHITE);
        // Fill the Progress Bar
        display.fillRect(0, 35, progress, 10, WHITE);
        
        display.display();
        
        if (elapsed >= holdDuration) {
            // Success Animation
            for (int i = 0; i < 4; i++) {
                display.clearDisplay();
                display.setCursor(30, 25);
                display.print("CLEANING");
                for (int j = 0; j <= i; j++) display.print(".");
                display.display();
                delay(200);
            }
            
            SD.remove("/data.csv");
            Serial.println("SD Card Wiped.");
            ESP.restart(); // Restart to re-initialize everything
        }
    }
}

// ==============================================================================
// MAIN LOOP
// ==============================================================================
void setup() {
    Serial.begin(115200);
    pinMode(BOOT_BUTTON, INPUT_PULLUP);
    
    for (int n = 0; n < 6; n++) {
        for (int i = 0; i < RSSI_WINDOW; i++) rssiHistory[n][i] = -100;
    }

    display.begin(SSD1306_SWITCHCAPVCC, 0x3C);
    display.clearDisplay();
    display.setTextColor(WHITE);
    rtc.begin();
    
    if (SD.begin(SD_CS_PIN)) {
        sdStatus = true;
        File file = SD.open("/data.csv", FILE_APPEND);
        if (file && file.size() == 0) {
            file.println("Timestamp,N1_Data,N2_Data,N3_Data,N4_Data,N5_Data");
        }
        file.close();
    }

    startESPNOW();
}

void loop() {
    if (digitalRead(BOOT_BUTTON) == LOW) handleSDWipe();
    if (!isSyncing) processAndLog();

    if (!isSyncing) {
        bool timeToSync = (millis() - lastSyncTime >= SYNC_COOLDOWN);
        unsigned long timeSinceLastPacket = millis() - lastRecvTime;
        bool isSafeWindow = (timeSinceLastPacket > 300000) && (timeSinceLastPacket < 600000);

        if (timeToSync && isSafeWindow && lastRecvTime != 0) {
            syncToSupabase();
        }
    }

    if (!isSyncing && (millis() - lastScreenUpdate > 1000)) {
        lastScreenUpdate = millis();
        DateTime now = rtc.now();
        display.clearDisplay();
        display.setCursor(0,0);
        display.printf("%02d:%02d:%02d SD:%s", now.hour(), now.minute(), now.second(), sdStatus ? "OK" : "!!");
        display.drawLine(0, 9, 128, 9, WHITE);

        for (int i = 1; i <= 5; i++) {
            int col = (i <= 3) ? 0 : 68;
            int row = 13 + ((i-1) % 3) * 13; 
            display.setCursor(col, row);
            unsigned long age = (millis() - nodeData[i].readingId) / 1000;
            if (age < 3600 && nodeData[i].id != 0) {
                display.printf("N%d:%d%% %dm", i, nodeData[i].battPct, (int)(age/60));
            } else {
                display.printf("N%d: --", i);
            }
        }
        
        display.drawLine(0, 52, 128, 52, WHITE); 
        display.setCursor(0, 55); 
        float avgRSSI = getSmoothedRSSI();
        if (millis() - lastRecvTime > 60000 || avgRSSI == 0) {
            display.print("Searching nodes...");
        } else {
            display.printf("Signal: %.1f dBm", avgRSSI);
            if (millis() - lastPulseTime < 500) display.fillCircle(124, 58, 1, WHITE); 
        }
        display.display();
    }
}

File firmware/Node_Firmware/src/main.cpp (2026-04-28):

/**
 * @file node_main.cpp
 * @brief Remote Sensor Node Firmware for Agricultural WSN Ground-Truthing
 * @description Reads capacitance soil moisture and BME280 data, calculates battery capacity,
 * transmits via ESP-NOW MAC protocol, and enters Deep Sleep to conserve energy.
 * @version 1.0.0
 */

#include <Arduino.h>
#include <esp_now.h>
#include <WiFi.h>
#include <esp_wifi.h> 
#include <Wire.h>
#include <Adafruit_Sensor.h>
#include <Adafruit_BME280.h>
#include "secrets.h"

// ==============================================================================
// CONFIGURATION & CALIBRATION
// ==============================================================================
#define NODE_ID 5 // IDENTIFIER: Change for each physical node

// Hub MAC Address format -> {0x25, 0x3A, 0x42, 0xCE, 0xB7, 0xFF}
uint8_t hubAddress[] = HUB_MAC_ADDRESS;

// --- Sleep Configuration ---
#define uS_TO_S_FACTOR 1000000ULL  // Conversion factor for micro seconds to seconds
#define TIME_TO_SLEEP  1800         // Sleep duration: 1800 seconds = 30 minutes

// --- Pin Definitions ---
const int SOIL_PIN = 34; 
const int BATT_PIN = 35; 

// ==============================================================================
// GLOBAL OBJECTS & MEMORY
// ==============================================================================
Adafruit_BME280 bme; 
esp_now_peer_info_t peerInfo;

extern "C" esp_err_t esp_wifi_internal_set_fix_rate(wifi_interface_t ifx, bool enable, wifi_phy_rate_t rate);

typedef struct struct_message {
    int id;
    float moisture;
    float temp;
    float humidity;
    int battPct;         
    unsigned int readingId;
} struct_message;

struct_message myData;

// RTC_DATA_ATTR ensures this variable survives Deep Sleep resets
RTC_DATA_ATTR unsigned int packetCount = 0; 

// Calibration variables loaded at boot
float battMultiplier;
int airVal;
int waterVal;

// ==============================================================================
// CALIBRATION DATABASE
// ==============================================================================
void loadCalibration() {
    switch(NODE_ID) {
        case 1:
            battMultiplier = 6.17; airVal = 3160; waterVal = 980; break;
        case 2:
            battMultiplier = 5.96; airVal = 3290; waterVal = 1040; break;
        case 3:
            battMultiplier = 6.25; airVal = 3190; waterVal = 1007; break;
        case 4:
            battMultiplier = 5.76; airVal = 2970; waterVal = 1010; break;
        case 5:
            battMultiplier = 6.13; airVal = 2830; waterVal = 940; break;
        default:
            battMultiplier = 6.0;  airVal = 3000; waterVal = 1000; break;
    }
}

// ==============================================================================
// MAIN LIFECYCLE
// ==============================================================================
void setup() {
    Serial.begin(115200);
    delay(500); // Brief stabilization delay

    loadCalibration(); 

    if (!bme.begin(0x77)) {
        Serial.println("[WARN] BME280 Initialization Failed!");
    } else {
      Serial.println("BME280 Initialized Sucessfully!");
    }

    // --- Radio Optimization & AMPDU Fix ---
    WiFi.mode(WIFI_STA);
    esp_wifi_stop(); 
    esp_wifi_deinit();
    
    wifi_init_config_t my_config = WIFI_INIT_CONFIG_DEFAULT();
    my_config.ampdu_tx_enable = false; 
    my_config.ampdu_rx_enable = false;
    esp_wifi_init(&my_config);
    esp_wifi_start();

    esp_wifi_set_promiscuous(true);
    esp_wifi_set_channel(1, WIFI_SECOND_CHAN_NONE);
    esp_wifi_set_promiscuous(false);

    WiFi.setTxPower(WIFI_POWER_19_5dBm);
    esp_wifi_internal_set_fix_rate(WIFI_IF_STA, true, WIFI_PHY_RATE_1M_L);
    
    if (esp_now_init() != ESP_OK) {
        Serial.println("[ERR] ESP-NOW Init Failed. Restarting...");
        ESP.restart();
    }

    memcpy(peerInfo.peer_addr, hubAddress, 6);
    peerInfo.channel = 1; 
    peerInfo.encrypt = false;
    
    if (esp_now_add_peer(&peerInfo) != ESP_OK) {
        Serial.println("[ERR] Failed to register Hub Peer");
    }
}

void loop() {
    // --- 1. Read Soil Moisture ---
    long soilSum = 0;
    for (int i = 0; i < 10; i++) {
        soilSum += analogRead(SOIL_PIN);
        delay(5);
    }
    int rawSoil = soilSum / 10;
    float moistureVal = map(rawSoil, airVal, waterVal, 0, 100);
    myData.moisture = constrain(moistureVal, 0.0, 100.0);

    // --- 2. Read BME280 Atmospheric Data ---
    myData.temp = bme.readTemperature();
    myData.humidity = bme.readHumidity();
    if (isnan(myData.temp)) myData.temp = 0.0;
    if (isnan(myData.humidity)) myData.humidity = 0.0;

    // --- 3. Read Battery Telemetry ---
    long batSum = 0;
    for (int i = 0; i < 10; i++) { 
        batSum += analogRead(BATT_PIN);
        delay(2);
    }
    float rawBatAvg = batSum / 10.0;
    float voltage = (rawBatAvg * 3.31 / 4095.0) * battMultiplier;
    
    // Map Li-ion curve: 3.5V (0%) to 4.2V (100%)
    float pctFloat = (voltage - 3.5) * (100.0 / 0.7);
    myData.battPct = (int)constrain(pctFloat, 0.0, 100.0);

    // --- 4. Package & Transmit ---
    myData.id = NODE_ID;
    myData.readingId = packetCount++;

    esp_err_t result = esp_now_send(hubAddress, (uint8_t *) &myData, sizeof(myData));
    
    // --- 5. Debug Output ---
    Serial.println("\n-------------------------------------------------");
    Serial.printf("NODE %d TELEMETRY (Packet %d)\n", NODE_ID, myData.readingId);
    Serial.printf("SOIL: Raw [%d] | Air: %d | Water: %d | Moist: %.1f%%\n", rawSoil, airVal, waterVal, myData.moisture);
    Serial.printf("ATMOS: Temp: %.2f*C | Humidity: %.2f%%\n", myData.temp, myData.humidity);
    Serial.printf("BATT: Raw [%.1f] | Mult: %.2f | Volt: %.2fV | Cap: %d%%\n", rawBatAvg, battMultiplier, voltage, myData.battPct);
    Serial.printf("UPLINK STATUS: %s\n", (result == ESP_OK) ? "SUCCESS" : "FAIL");
    Serial.println("-------------------------------------------------");

    // --- 6. Enter Deep Sleep ---
    Serial.printf("Entering Deep Sleep for %d seconds...\n", TIME_TO_SLEEP);
    delay(100); // Allow serial buffer to flush before power cut
    
    esp_sleep_enable_timer_wakeup(TIME_TO_SLEEP * uS_TO_S_FACTOR);
    esp_deep_sleep_start();
}

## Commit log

2026-04-25 Initial research and hardware commit
    [Central Hub.fzz, ESP32U Enclosure.f3d, ESP32U Enclosure.step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]
2026-04-27 Refactor: Replace Fritzing schematics with KiCad designs and Update docs
    [Central Hub.fzz, Node.fzz]
2026-04-28 Fixed typo within comments
    [main.cpp]

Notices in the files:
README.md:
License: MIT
